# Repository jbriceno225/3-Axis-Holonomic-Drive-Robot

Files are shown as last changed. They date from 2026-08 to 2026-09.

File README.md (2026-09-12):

# KiwiDrive — Three-Wheel Holonomic Robot

A work-in-progress mobile robotics platform built around three omni wheels, an ESP32 controller, quadrature encoders, custom mechanical design, and a ROS 2 workspace.

> **Project status:** active development. The repository contains the current design and software artifacts; physical-system validation is in progress.

## What is in this repository

- **Mechanical design:** Fusion 360 assemblies, STEP exports, and printable STL parts in [`CAD/`](CAD/).
- **Electronics:** KiCad Rev A project files, fabrication outputs, and a purchasing BOM in [`PCB/`](PCB/).
- **Embedded control:** ESP32 firmware for three motor channels, encoder feedback, PID velocity control, Bluetooth gamepad control, and a serial-command safety timeout in [`ESP32_Code/`](ESP32_Code/).
- **ROS 2 integration:** Robot-description files, RViz configuration, serial-command bridge code, and vendor dependencies in [`src/`](src/).

## System overview

```text
Operator / ROS 2 command
          |
          v
  Raspberry Pi + ROS 2 workspace
          |
          v
       Serial interface
          |
          v
ESP32 -> motor drivers -> three DC motors
  ^                              |
  +--------- quadrature encoders-+
```

The three-wheel omni-wheel layout is intended to support holonomic translation and rotation. Current software includes manual control and the foundations for command bridging, robot description, and odometry work.

## Repository layout

```text
CAD/          Fusion 360 sources, STEP exports, and 3D-printable parts
PCB/          Rev A KiCad design, Gerbers, drill files, and BOM
ESP32_Code/   ESP32 firmware
src/          ROS 2 description, serial bridge, and third-party dependencies
patches/      Local patch overlays for selected dependencies
```

## Current development focus

- Integrating ESP32 motor control, encoder feedback, and safety behavior.
- Building out the ROS 2 robot description and serial bridge.
- Validating wheel kinematics, odometry, and hardware behavior through staged testing.
- Documenting CAD, PCB, firmware, and ROS 2 interfaces as the system matures.

## Safety

Test with the drive wheels raised during initial firmware and controller checks. Use an accessible physical power cutoff for floor testing; a software timeout is not a substitute for a physical emergency stop.

## Tools

**Mechanical:** Fusion 360, STEP, STL, 3D printing  
**Electronics:** KiCad, ESP32, TB6612FNG motor drivers, quadrature encoders  
**Software:** C/C++, Python, ROS 2, PID control, serial communication

## License

This project is licensed under the [MIT License](LICENSE).

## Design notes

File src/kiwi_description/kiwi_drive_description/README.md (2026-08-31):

# Kiwi_Drive_Full_Assembly_Copy_Copy — Robot Description

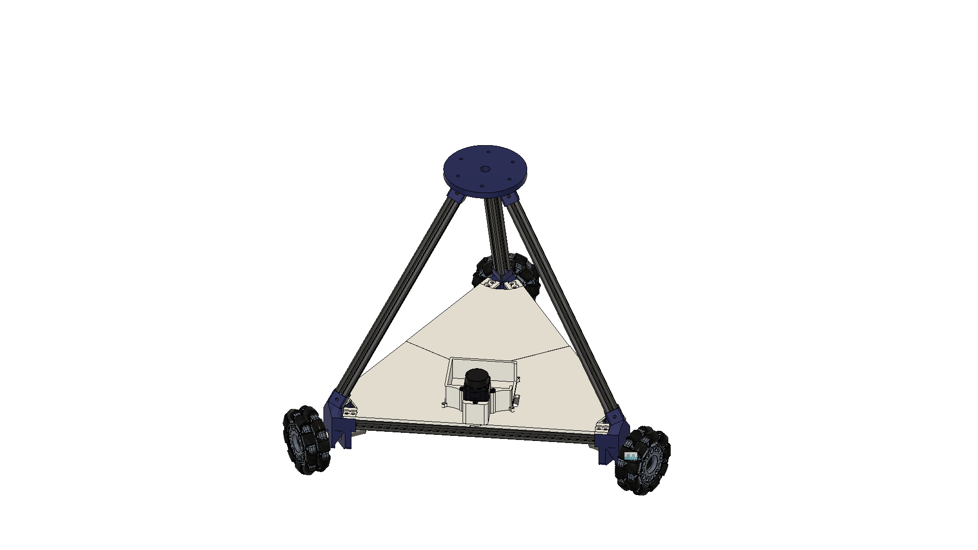
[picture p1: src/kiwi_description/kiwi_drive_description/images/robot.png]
Kiwi_Drive_Full_Assembly_Copy_Copy


## Overview

| Property | Value |
|---|---|
| Total mass | 18.172 kg |
| Links | 5 |
| Joints | 4 (3 movable) |
| Assemblies | 17 |
| Root link | `base_link` |

## Table of Contents

- [Kinematic Tree](#kinematic-tree)
- [Link Properties](#link-properties)
- [Joint Properties](#joint-properties)
- [Assembly Breakdown](#assembly-breakdown)
- [Quick Start (ROS 2)](#quick-start-ros-2)
- [Files](#files)

## Kinematic Tree

```
base_link [BAKE]
  └─ wheel_1_to_base_link [continuous]
    wheel_1_link_Omni_Wheel [BAKE]
  └─ wheel_2_to_base_link [continuous]
    wheel_2_link_Omni_Wheel [BAKE]
  └─ wheel_3_to_base_link [continuous]
    wheel_3_link_Omni_Wheel [BAKE]
  └─ base_link_to_lidar_link [fixed]
    Lidar_Mounting_Plate
```

## Link Properties

| Link | Mass (kg) | Material | Collision | Bodies |
|---|---|---|---|---|
| `Lidar_Mounting_Plate` | 1.0862 | Steel | box | 1 |
| `base_link` | 11.6921 | Steel | box | 1 |
| `wheel_1_link_Omni_Wheel` | 1.7978 | Steel | box | 60 |
| `wheel_2_link_Omni_Wheel` | 1.7978 | Steel | box | 60 |
| `wheel_3_link_Omni_Wheel` | 1.7978 | Steel | box | 60 |

## Joint Properties

| Joint | Type | Parent → Child | Axis | Limits |
|---|---|---|---|---|
| `base_link_to_lidar_link` | fixed | `base_link` → `Lidar_Mounting_Plate` | (0,0,1) | — |
| `wheel_1_to_base_link` | continuous | `base_link` → `wheel_1_link_Omni_Wheel` | (0,0,1) | — |
| `wheel_2_to_base_link` | continuous | `base_link` → `wheel_2_link_Omni_Wheel` | (0,0,1) | — |
| `wheel_3_to_base_link` | continuous | `base_link` → `wheel_3_link_Omni_Wheel` | (0,0,1) | — |

## Assembly Breakdown

### A1_ASM

- **Links**: 
- **Total mass**: 0.000 kg

### Battery_Mount_Assembly

- **Links**: 
- **Total mass**: 0.000 kg

### Converter_DCDC_RECOM_R_78E_0_5_THT

- **Links**: 
- **Total mass**: 0.000 kg

### LD19_LiDAR

- **Links**: 
- **Total mass**: 0.000 kg

### Main_PCB

- **Links**: 
- **Total mass**: 0.000 kg

### OmniWheelwithHub

- **Links**: 
- **Total mass**: 0.000 kg

### Omni_Wheel

- **Links**: 
- **Total mass**: 0.000 kg

### PCB_Housing

- **Links**: 
- **Total mass**: 0.000 kg

### PinHeader_1x02_P2_54mm_Vertical

- **Links**: 
- **Total mass**: 0.000 kg

### PinHeader_1x04_P2_54mm_Vertical

- **Links**: 
- **Total mass**: 0.000 kg

### PinHeader_1x10_P2_54mm_Vertical

- **Links**: 
- **Total mass**: 0.000 kg

### Wheel_Hub

- **Links**: 
- **Total mass**: 0.000 kg

### base_link

- **Links**: base_link
- **Total mass**: 11.692 kg

### lidar_link

- **Links**: Lidar_Mounting_Plate
- **Total mass**: 1.086 kg

### wheel_1_link

- **Links**: wheel_1_link_Omni_Wheel
- **Total mass**: 1.798 kg

### wheel_2_link

- **Links**: wheel_2_link_Omni_Wheel
- **Total mass**: 1.798 kg

### wheel_3_link

- **Links**: wheel_3_link_Omni_Wheel
- **Total mass**: 1.798 kg

## Quick Start (ROS 2)

```bash
# 1. Copy package to your ROS 2 workspace
cp -r kiwi_drive_description ~/ros2_ws/src/

# 2. Build
cd ~/ros2_ws
colcon build --packages-select kiwi_drive_description
source install/setup.bash

# 3. Visualize in RViz2
ros2 launch kiwi_drive_description display.launch.py

# 4. Validate URDF structure
check_urdf install/kiwi_drive_description/share/kiwi_drive_description/urdf/Kiwi_Drive_Full_Assembly_Copy_Copy.urdf

# 5. Print kinematic tree
urdf_to_graphviz install/kiwi_drive_description/share/kiwi_drive_description/urdf/Kiwi_Drive_Full_Assembly_Copy_Copy.urdf
```

**Joint control**: The launch file includes `joint_state_publisher_gui` —
use the sliders to move revolute/prismatic joints in RViz2.

**Topic inspection**:
```bash
# See published joint states
ros2 topic echo /joint_states

# See robot description parameter
ros2 param get /robot_state_publisher robot_description
```

## Files

| Path | Description |
|---|---|
| `urdf/Kiwi_Drive_Full_Assembly_Copy_Copy.urdf.xacro` | Top-level xacro (entry point) |
| `urdf/Kiwi_Drive_Full_Assembly_Copy_Copy.urdf` | Flat URDF (for validation) |
| `urdf/assemblies/` | Per-assembly xacro macros |
| `meshes/` | Visual (OBJ) and collision (STL) meshes |
| `launch/display.launch.py` | Launch robot_state_publisher, RViz, and generated controllers |
| `config/joint_state.yaml` | Joint state publisher config |
| `config/ros2_controllers.yaml` | Generated ros2_control controller manager config |
| `robot_data.yaml` | Supplementary data (beyond URDF) |
| `docs/transforms.md` | Transformation matrices (KaTeX) |

## Customizing

Assemblies tagged `!dummy_` are designed to be swapped out. To replace one:

1. Create your replacement as a xacro macro with the same interface
2. Place it in `urdf/assemblies/`
3. Update the `<xacro:include>` in `urdf/Kiwi_Drive_Full_Assembly_Copy_Copy.urdf.xacro`
4. Update meshes in `meshes/<your_assembly>/`

The xacro prefix system (`${prefix}`) ensures link names stay unique
when multiple instances of the same assembly are used.

---
*Generated by Fusion URDF/XACRO Exporter v3.1.0*

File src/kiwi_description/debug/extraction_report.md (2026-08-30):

# Extraction Report: Kiwi_Drive_Full_Assembly-Copy-Copy

**Exported:** 2026-08-30T14:10:05.508802
**Exporter:** v3.1.0

## Summary

| Metric | Value |
|---|---|
| Occurrences | 201 |
| Subassemblies | 28 |
| Leaf components | 173 |
| Joints (total) | 4 |
| As-built joints | 3 |
| Regular joints | 1 |
| Max nesting depth | 5 |

## Assembly Hierarchy

```
[Kiwi_Drive_Full_Assembly_Copy_Copy]  (design root)
  [base_link]  (depth=0, children=19)
    ├── 2020_400mm_Aluminum_Extrusion  (570.3g, Steel)
    ├── 2020_400mm_Aluminum_Extrusion  (570.3g, Steel)
    ├── 2020_400mm_Aluminum_Extrusion  (570.3g, Steel)
    ├── 2020_400mm_Aluminum_Extrusion  (570.3g, Steel)
    ├── 2020_400mm_Aluminum_Extrusion  (570.3g, Steel)
    ├── 2020_400mm_Aluminum_Extrusion  (570.3g, Steel)
    ├── 2020_Aluminum_Extrusion_Mounting_Spacer  (37.6g, Steel)
    ├── Front_Left_Base_Plate  (1381.7g, Steel)
    ├── Front_Right_Base_Plate  (1387.0g, Steel)
    ├── JGA25_370DC_Motor  (204.4g, Steel)
    ├── JGA25_370DC_Motor  (204.4g, Steel)
    ├── JGA25_370DC_Motor  (204.4g, Steel)
    ├── Motor_Mount  (436.3g, Steel)
    ├── Motor_Mount  (436.3g, Steel)
    ├── Motor_Mount  (436.3g, Steel)
    ├── Rear_Base_Plate  (1396.3g, Steel)
    ├── Top_Plate  (1175.2g, Steel)
    [Battery_Mount_Assembly]  (depth=1, children=2)
      ├── Battery_Mount_Back  (155.2g, Steel)
      ├── Battery_Mount_Front  (106.3g, Steel)
    [PCB_Housing]  (depth=1, children=3)
      ├── PCBoutline  (63.8g, Steel)
      ├── PCM_Mounting_Enclosure  (540.1g, Steel)
      [Main_PCB]  (depth=2, children=5)
        ├── KiwiDrive_PCB  (94.6g, Steel)
        [Converter_DCDC_RECOM_R_78E_0_5_THT]  (depth=3, children=1)
          ├── Converter_DCDC_RECOM_R_78E_05_THT  (8.1g, Steel)
        [PinHeader_1x02_P2_54mm_Vertical]  (depth=3, children=1)
          ├── PinHeader_1x02_P254mm_Vertical  (0.3g, Steel)
        [PinHeader_1x04_P2_54mm_Vertical]  (depth=3, children=1)
          ├── PinHeader_1x04_P254mm_Vertical  (0.6g, Steel)
        [PinHeader_1x10_P2_54mm_Vertical]  (depth=3, children=1)
          ├── PinHeader_1x10_P254mm_Vertical  (1.5g, Steel)
  [lidar_link]  (depth=0, children=2)
    ├── Lidar_Mounting_Plate  (982.9g, Steel)
    [LD19_LiDAR]  (depth=1, children=8)
      ├── LD19_PCB  (8.8g, Steel)
      ├── LD19_bottom  (22.8g, Steel)
      ├── LD19_middle  (51.2g, Steel)
      ├── LD19_up  (20.0g, Steel)
      ├── PA2X6_1  (0.1g, Steel)
      ├── PA2X6_2  (0.1g, Steel)
      ├── PA2X6_3  (0.1g, Steel)
      ├── PA2X6_4  (0.1g, Steel)
  [wheel_1_link]  (depth=0, children=3)
    ├── 4mm_Rigid_Flange_Coupling  (3.5g, Aluminum)
    ├── Omni_Wheel  (1479.8g, Steel)
  [wheel_2_link]  (depth=0, children=3)
    ├── 4mm_Rigid_Flange_Coupling  (3.5g, Aluminum)
    ├── Omni_Wheel  (1479.8g, Steel)
  [wheel_3_link]  (depth=0, children=3)
    ├── 4mm_Rigid_Flange_Coupling  (3.5g, Aluminum)
    ├── Omni_Wheel  (1479.8g, Steel)
    [Wheel_Hub]  (depth=1, children=2)
      ├── Motor_Hub  (119.0g, Steel)
      ├── Motor_Hub  (119.0g, Steel)
      ├── Motor_Hub  (119.0g, Steel)
      [OmniWheelwithHub]  (depth=2, children=3)
        ├── 6mm_Mount  (7.0g, Generic)
        ├── 6mm_Mount  (7.0g, Generic)
        ├── 6mm_Mount  (7.0g, Generic)
        ├── Back_Spacer  (2.4g, Generic)
        ├── Back_Spacer  (2.4g, Generic)
        ├── Back_Spacer  (2.4g, Generic)
        [Omni_Wheel]  (depth=3, children=3)
          ├── F12  (12.4g, Generic)
          ├── F12  (12.4g, Generic)
          ├── F12  (12.4g, Generic)
          [A1_ASM]  (depth=4, children=20)
            ├── F2  (21.2g, Generic)
            ├── F2  (21.2g, Generic)
            ├── F2  (21.2g, Generic)
            ├── F2  (21.2g, Generic)
            ├── F2  (21.2g, Generic)
            ├── F2  (21.2g, Generic)
            ├── F2  (21.2g, Generic)
            ├── F2  (21.2g, Generic)
            ├── F2  (21.2g, Generic)
            ├── F2  (21.2g, Generic)
            ├── F2  (21.2g, Generic)
            ├── F2  (21.2g, Generic)
            ├── F5  (4.8g, Generic)
            ├── F5  (4.8g, Generic)
            ├── F5  (4.8g, Generic)
            ├── F5  (4.8g, Generic)
            ├── F5  (4.8g, Generic)
            ├── F5  (4.8g, Generic)
            ├── F5  (4.8g, Generic)
            ├── F5  (4.8g, Generic)
            ├── F5  (4.8g, Generic)
            ├── F5  (4.8g, Generic)
            ├── F5  (4.8g, Generic)
            ├── F5  (4.8g, Generic)
            ├── F5  (4.8g, Generic)
            ├── F5  (4.8g, Generic)
            ├── F5  (4.8g, Generic)
            ├── F5  (4.8g, Generic)
            ├── F5  (4.8g, Generic)
            ├── F5  (4.8g, Generic)
            ├── F5  (4.8g, Generic)
            ├── F5  (4.8g, Generic)
            ├── F5  (4.8g, Generic)
            ├── F5  (4.8g, Generic)
            ├── F5  (4.8g, Generic)
            ├── F5  (4.8g, Generic)
            ├── F5  (4.8g, Generic)
            ├── F5  (4.8g, Generic)
            ├── F5  (4.8g, Generic)
            ├── F5  (4.8g, Generic)
            ├── F5  (4.8g, Generic)
            ├── F5  (4.8g, Generic)
            ├── F5  (4.8g, Generic)
            ├── F5  (4.8g, Generic)
            ├── F5  (4.8g, Generic)
            ├── F5  (4.8g, Generic)
            ├── F5  (4.8g, Generic)
            ├── F5  (4.8g, Generic)
            ├── F5  (4.8g, Generic)
            ├── F5  (4.8g, Generic)
            ├── F5  (4.8g, Generic)
            ├── F5  (4.8g, Generic)
            ├── F5  (4.8g, Generic)
            ├── F5  (4.8g, Generic)
            ├── F5  (4.8g, Generic)
            ├── F5  (4.8g, Generic)
            ├── F5  (4.8g, Generic)
            ├── F5  (4.8g, Generic)
            ├── F5  (4.8g, Generic)
            ├── F5  (4.8g, Generic)
            ├── F5  (4.8g, Generic)
            ├── F5  (4.8g, Generic)
            ├── F5  (4.8g, Generic)
            ├── F5  (4.8g, Generic)
            ├── F5  (4.8g, Generic)
            ├── F5  (4.8g, Generic)
            ├── F6  (0.2g, Generic)
            ├── F6  (0.2g, Generic)
            ├── F6  (0.2g, Generic)
            ├── F6  (0.2g, Generic)
            ├── F6  (0.2g, Generic)
            ├── F6  (0.2g, Generic)
            ├── F6  (0.2g, Generic)
            ├── F6  (0.2g, Generic)
            ├── F6  (0.2g, Generic)
            ├── F6  (0.2g, Generic)
            ├── F6  (0.2g, Generic)
            ├── F6  (0.2g, Generic)
            ├── F6  (0.2g, Generic)
            ├── F6  (0.2g, Generic)
            ├── F6  (0.2g, Generic)
            ├── F6  (0.2g, Generic)
            ├── F6  (0.2g, Generic)
            ├── F6  (0.2g, Generic)
            ├── F6  (0.2g, Generic)
            ├── F6  (0.2g, Generic)
            ├── F6  (0.2g, Generic)
            ├── F6  (0.2g, Generic)
            ├── F6  (0.2g, Generic)
            ├── F6  (0.2g, Generic)
            ├── F6  (0.2g, Generic)
            ├── F6  (0.2g, Generic)
            ├── F6  (0.2g, Generic)
            ├── F6  (0.2g, Generic)
            ├── F6  (0.2g, Generic)
            ├── F6  (0.2g, Generic)
            ├── F6  (0.2g, Generic)
            ├── F6  (0.2g, Generic)
            ├── F6  (0.2g, Generic)
            ├── F6  (0.2g, Generic)
            ├── F6  (0.2g, Generic)
            ├── F6  (0.2g, Generic)
            ├── F6  (0.2g, Generic)
            ├── F6  (0.2g, Generic)
            ├── F6  (0.2g, Generic)
            ├── F6  (0.2g, Generic)
            ├── F6  (0.2g, Generic)
            ├── F6  (0.2g, Generic)
            ├── F6  (0.2g, Generic)
            ├── F6  (0.2g, Generic)
            ├── F6  (0.2g, Generic)
            ├── F6  (0.2g, Generic)
            ├── F6  (0.2g, Generic)
            ├── F6  (0.2g, Generic)
            ├── F6  (0.2g, Generic)
            ├── F6  (0.2g, Generic)
            ├── F6  (0.2g, Generic)
            ├── F6  (0.2g, Generic)
            ├── F6  (0.2g, Generic)
            ├── F6  (0.2g, Generic)
```

## Occurrences

### Depth 0

#### 📦 SUBASSEMBLY: `base_link`

| Property | Value |
|---|---|
| Full path | `base_link:1` |
| Component name | base_link |
| Depth | 0 |
| Path segments | base_link |
| Child occurrences | 19 |
| **Transforms** | |
| Global position (m) | (0.000000, 0.000000, 0.000000) |
| Global position (mm) | (0.00, 0.00, 0.00) |
| Local transform (m) | (0.000000, 0.000000, 0.000000) |
| Assembly context depth | 0 |
| transform2 (m) | (0.000000, 0.000000, 0.000000) |

#### 📦 SUBASSEMBLY: `lidar_link`

| Property | Value |
|---|---|
| Full path | `lidar_link:1` |
| Component name | lidar_link |
| Depth | 0 |
| Path segments | lidar_link |
| Child occurrences | 2 |
| **Transforms** | |
| Global position (m) | (-0.000000, -0.000885, -0.000101) |
| Global position (mm) | (-0.00, -0.88, -0.10) |
| Local transform (m) | (-0.000000, -0.000885, -0.000101) |
| Assembly context depth | 0 |
| transform2 (m) | (-0.000000, -0.000885, -0.000101) |

#### 📦 SUBASSEMBLY: `wheel_1_link`

| Property | Value |
|---|---|
| Full path | `wheel_1_link:1` |
| Component name | wheel_1_link |
| Depth | 0 |
| Path segments | wheel_1_link |
| Child occurrences | 3 |
| **Transforms** | |
| Global position (m) | (0.000000, 0.000000, 0.000000) |
| Global position (mm) | (0.00, 0.00, 0.00) |
| Local transform (m) | (0.000000, 0.000000, 0.000000) |
| Assembly context depth | 0 |
| transform2 (m) | (0.000000, 0.000000, 0.000000) |

#### 📦 SUBASSEMBLY: `wheel_2_link`

| Property | Value |
|---|---|
| Full path | `wheel_2_link:1` |
| Component name | wheel_2_link |
| Depth | 0 |
| Path segments | wheel_2_link |
| Child occurrences | 3 |
| **Transforms** | |
| Global position (m) | (0.000000, 0.000000, 0.000000) |
| Global position (mm) | (0.00, 0.00, 0.00) |
| Local transform (m) | (0.000000, 0.000000, 0.000000) |
| Assembly context depth | 0 |
| transform2 (m) | (0.000000, 0.000000, 0.000000) |

#### 📦 SUBASSEMBLY: `wheel_3_link`

| Property | Value |
|---|---|
| Full path | `wheel_3_link:1` |
| Component name | wheel_3_link |
| Depth | 0 |
| Path segments | wheel_3_link |
| Child occurrences | 3 |
| **Transforms** | |
| Global position (m) | (0.000000, 0.000000, 0.000000) |
| Global position (mm) | (0.00, 0.00, 0.00) |
| Local transform (m) | (0.000000, 0.000000, 0.000000) |
| Assembly context depth | 0 |
| transform2 (m) | (0.000000, 0.000000, 0.000000) |

### Depth 1

#### 🔧 COMPONENT: `2020_400mm_Aluminum_Extrusion`

| Property | Value |
|---|---|
| Full path | `base_link:1+2020_400mm_Aluminum_Extrusion:1` |
| Component name | 2020_400mm_Aluminum_Extrusion |
| Depth | 1 |
| Path segments | base_link → 2020_400mm_Aluminum_Extrusion |
| Parent path | `base_link:1` |
| **Transforms** | |
| Global position (m) | (-0.180000, -0.129904, -0.000000) |
| Global position (mm) | (-180.00, -129.90, -0.00) |
| Local transform (m) | (-0.180000, -0.129904, -0.000000) |
| Assembly context depth | 1 |
| transform2 (m) | (-0.180000, -0.129904, -0.000000) |
| **Physical** | |
| Mass | 0.570259 kg (570.259 g) |
| Volume | 7.264445e-05 m³ |
| Density | 7850.0 kg/m³ |
| Surface area | 6.785414e-02 m² |
| Body count | 1 |
| CoM (component-local, m) | (0.000000, 0.180000, 0.000000) |
| CoM (global, m) | (-0.180000, 0.050096, 0.000000) |
| CoM (global, mm) | (-180.00, 50.10, 0.00) |
| **Inertia at origin (kg·m²)** | |
| Ixx, Iyy, Izz | 2.610302e-02, 4.636788e-05, 2.610302e-02 |
| Ixy, Ixz, Iyz | -4.801159e-12, 1.977162e-13, 2.096710e-13 |
| **Inertia at CoM (kg·m²)** | |
| Ixx, Iyy, Izz | 7.626636e-03, 4.636788e-05, 7.626636e-03 |
| Ixy, Ixz, Iyz | -7.710703e-13, 1.977162e-13, 5.725726e-12 |
| Bounding box (m) | 0.0200 × 0.4000 × 0.0200 |
| Bounding box (mm) | 20.00 × 400.00 × 20.00 |
| **Material & Appearance** | |
| Material | Steel |
| Appearance | Paint_Metallic_Black |
| Color (RGB 0-1) | (0.349, 0.349, 0.349) |
| Color (RGB 0-255) | (89, 89, 89) |

#### 🔧 COMPONENT: `2020_400mm_Aluminum_Extrusion`

| Property | Value |
|---|---|
| Full path | `base_link:1+2020_400mm_Aluminum_Extrusion:4` |
| Component name | 2020_400mm_Aluminum_Extrusion |
| Depth | 1 |
| Path segments | base_link → 2020_400mm_Aluminum_Extrusion |
| Parent path | `base_link:1` |
| **Transforms** | |
| Global position (m) | (-0.202500, -0.090933, 0.000000) |
| Global position (mm) | (-202.50, -90.93, 0.00) |
| Local transform (m) | (-0.202500, -0.090933, 0.000000) |
| Assembly context depth | 1 |
| transform2 (m) | (-0.202500, -0.090933, 0.000000) |
| **Physical** | |
| Mass | 0.570259 kg (570.259 g) |
| Volume | 7.264445e-05 m³ |
| Density | 7850.0 kg/m³ |
| Surface area | 6.785414e-02 m² |
| Body count | 1 |
| CoM (component-local, m) | (0.000000, 0.180000, 0.000000) |
| CoM (global, m) | (-0.202500, 0.089067, 0.000000) |
| CoM (global, mm) | (-202.50, 89.07, 0.00) |
| **Inertia at origin (kg·m²)** | |
| Ixx, Iyy, Izz | 2.610302e-02, 4.636788e-05, 2.610302e-02 |
| Ixy, Ixz, Iyz | -4.801159e-12, 1.977162e-13, 2.096710e-13 |
| **Inertia at CoM (kg·m²)** | |
| Ixx, Iyy, Izz | 7.626636e-03, 4.636788e-05, 7.626636e-03 |
| Ixy, Ixz, Iyz | -7.710703e-13, 1.977162e-13, 5.725726e-12 |
| Bounding box (m) | 0.0200 × 0.4000 × 0.0200 |
| Bounding box (mm) | 20.00 × 400.00 × 20.00 |
| **Material & Appearance** | |
| Material | Steel |
| Appearance | Paint_Metallic_Black |
| Color (RGB 0-1) | (0.349, 0.349, 0.349) |
| Color (RGB 0-255) | (89, 89, 89) |

#### 🔧 COMPONENT: `2020_400mm_Aluminum_Extrusion`

| Property | Value |
|---|---|
| Full path | `base_link:1+2020_400mm_Aluminum_Extrusion:5` |
| Component name | 2020_400mm_Aluminum_Extrusion |
| Depth | 1 |
| Path segments | base_link → 2020_400mm_Aluminum_Extrusion |
| Parent path | `base_link:1` |
| **Transforms** | |
| Global position (m) | (0.202500, -0.090933, 0.000000) |
| Global position (mm) | (202.50, -90.93, 0.00) |
| Local transform (m) | (0.202500, -0.090933, 0.000000) |
| Assembly context depth | 1 |
| transform2 (m) | (0.202500, -0.090933, 0.000000) |
| **Physical** | |
| Mass | 0.570259 kg (570.259 g) |
| Volume | 7.264445e-05 m³ |
| Density | 7850.0 kg/m³ |
| Surface area | 6.785414e-02 m² |
| Body count | 1 |
| CoM (component-local, m) | (0.000000, 0.180000, 0.000000) |
| CoM (global, m) | (0.202500, 0.089067, 0.000000) |
| CoM (global, mm) | (202.50, 89.07, 0.00) |
| **Inertia at origin (kg·m²)** | |
| Ixx, Iyy, Izz | 2.610302e-02, 4.636788e-05, 2.610302e-02 |
| Ixy, Ixz, Iyz | -4.801159e-12, 1.977162e-13, 2.096710e-13 |
| **Inertia at CoM (kg·m²)** | |
| Ixx, Iyy, Izz | 7.626636e-03, 4.636788e-05, 7.626636e-03 |
| Ixy, Ixz, Iyz | -7.710703e-13, 1.977162e-13, 5.725726e-12 |
| Bounding box (m) | 0.0200 × 0.4000 × 0.0200 |
| Bounding box (mm) | 20.00 × 400.00 × 20.00 |
| **Material & Appearance** | |
| Material | Steel |
| Appearance | Paint_Metallic_Black |
| Color (RGB 0-1) | (0.349, 0.349, 0.349) |
| Color (RGB 0-255) | (89, 89, 89) |

#### 🔧 COMPONENT: `2020_400mm_Aluminum_Extrusion`

| Property | Value |
|---|---|
| Full path | `base_link:1+2020_400mm_Aluminum_Extrusion:7` |
| Component name | 2020_400mm_Aluminum_Extrusion |
| Depth | 1 |
| Path segments | base_link → 2020_400mm_Aluminum_Extrusion |
| Parent path | `base_link:1` |
| **Transforms** | |
| Global position (m) | (0.202839, -0.117109, 0.041859) |
| Global position (mm) | (202.84, -117.11, 41.86) |
| Local transform (m) | (0.202839, -0.117109, 0.041859) |
| Assembly context depth | 1 |
| transform2 (m) | (0.202839, -0.117109, 0.041859) |
| **Physical** | |
| Mass | 0.570259 kg (570.259 g) |
| Volume | 7.264445e-05 m³ |
| Density | 7850.0 kg/m³ |
| Surface area | 6.785414e-02 m² |
| Body count | 1 |
| CoM (component-local, m) | (0.000000, 0.180000, 0.000000) |
| CoM (global, m) | (0.202839, 0.062891, 0.041859) |
| CoM (global, mm) | (202.84, 62.89, 41.86) |
| **Inertia at origin (kg·m²)** | |
| Ixx, Iyy, Izz | 2.610302e-02, 4.636788e-05, 2.610302e-02 |
| Ixy, Ixz, Iyz | -4.801159e-12, 1.977162e-13, 2.096710e-13 |
| **Inertia at CoM (kg·m²)** | |
| Ixx, Iyy, Izz | 7.626636e-03, 4.636788e-05, 7.626636e-03 |
| Ixy, Ixz, Iyz | -7.710703e-13, 1.977162e-13, 5.725726e-12 |
| Bounding box (m) | 0.0200 × 0.4000 × 0.0200 |
| Bounding box (mm) | 20.00 × 400.00 × 20.00 |
| **Material & Appearance** | |
| Material | Steel |
| Appearance | Paint_Metallic_Black |
| Color (RGB 0-1) | (0.349, 0.349, 0.349) |
| Color (RGB 0-255) | (89, 89, 89) |

#### 🔧 COMPONENT: `2020_400mm_Aluminum_Extrusion`

| Property | Value |
|---|---|
| Full path | `base_link:1+2020_400mm_Aluminum_Extrusion:8` |
| Component name | 2020_400mm_Aluminum_Extrusion |
| Depth | 1 |
| Path segments | base_link → 2020_400mm_Aluminum_Extrusion |
| Parent path | `base_link:1` |
| **Transforms** | |
| Global position (m) | (-0.202839, -0.117109, 0.041859) |
| Global position (mm) | (-202.84, -117.11, 41.86) |
| Local transform (m) | (-0.202839, -0.117109, 0.041859) |
| Assembly context depth | 1 |
| transform2 (m) | (-0.202839, -0.117109, 0.041859) |
| **Physical** | |
| Mass | 0.570259 kg (570.259 g) |
| Volume | 7.264445e-05 m³ |
| Density | 7850.0 kg/m³ |
| Surface area | 6.785414e-02 m² |
| Body count | 1 |
| CoM (component-local, m) | (0.000000, 0.180000, 0.000000) |
| CoM (global, m) | (-0.202839, 0.062891, 0.041859) |
| CoM (global, mm) | (-202.84, 62.89, 41.86) |
| **Inertia at origin (kg·m²)** | |
| Ixx, Iyy, Izz | 2.610302e-02, 4.636788e-05, 2.610302e-02 |
| Ixy, Ixz, Iyz | -4.801159e-12, 1.977162e-13, 2.096710e-13 |
| **Inertia at CoM (kg·m²)** | |
| Ixx, Iyy, Izz | 7.626636e-03, 4.636788e-05, 7.626636e-03 |
| Ixy, Ixz, Iyz | -7.710703e-13, 1.977162e-13, 5.725726e-12 |
| Bounding box (m) | 0.0200 × 0.4000 × 0.0200 |
| Bounding box (mm) | 20.00 × 400.00 × 20.00 |
| **Material & Appearance** | |
| Material | Steel |
| Appearance | Paint_Metallic_Black |
| Color (RGB 0-1) | (0.349, 0.349, 0.349) |
| Color (RGB 0-255) | (89, 89, 89) |

#### 🔧 COMPONENT: `2020_400mm_Aluminum_Extrusion`

| Property | Value |
|---|---|
| Full path | `base_link:1+2020_400mm_Aluminum_Extrusion:9` |
| Component name | 2020_400mm_Aluminum_Extrusion |
| Depth | 1 |
| Path segments | base_link → 2020_400mm_Aluminum_Extrusion |
| Parent path | `base_link:1` |
| **Transforms** | |
| Global position (m) | (0.000000, 0.046452, 0.349013) |
| Global position (mm) | (0.00, 46.45, 349.01) |
| Local transform (m) | (0.000000, 0.046452, 0.349013) |
| Assembly context depth | 1 |
| transform2 (m) | (0.000000, 0.046452, 0.349013) |
| **Physical** | |
| Mass | 0.570259 kg (570.259 g) |
| Volume | 7.264445e-05 m³ |
| Density | 7850.0 kg/m³ |
| Surface area | 6.785414e-02 m² |
| Body count | 1 |
| CoM (component-local, m) | (0.000000, 0.180000, 0.000000) |
| CoM (global, m) | (0.000000, 0.226452, 0.349013) |
| CoM (global, mm) | (0.00, 226.45, 349.01) |
| **Inertia at origin (kg·m²)** | |
| Ixx, Iyy, Izz | 2.610302e-02, 4.636788e-05, 2.610302e-02 |
| Ixy, Ixz, Iyz | -4.801159e-12, 1.977162e-13, 2.096710e-13 |
| **Inertia at CoM (kg·m²)** | |
| Ixx, Iyy, Izz | 7.626636e-03, 4.636788e-05, 7.626636e-03 |
| Ixy, Ixz, Iyz | -7.710703e-13, 1.977162e-13, 5.725726e-12 |
| Bounding box (m) | 0.0200 × 0.4000 × 0.0200 |
| Bounding box (mm) | 20.00 × 400.00 × 20.00 |
| **Material & Appearance** | |
| Material | Steel |
| Appearance | Paint_Metallic_Black |
| Color (RGB 0-1) | (0.349, 0.349, 0.349) |
| Color (RGB 0-255) | (89, 89, 89) |

#### 🔧 COMPONENT: `2020_Aluminum_Extrusion_Mounting_Spacer`

| Property | Value |
|---|---|
| Full path | `base_link:1+2020_Aluminum_Extrusion_Mounting_Spacer:1` |
| Component name | 2020_Aluminum_Extrusion_Mounting_Spacer |
| Depth | 1 |
| Path segments | base_link → 2020_Aluminum_Extrusion_Mounting_Spacer |
| Parent path | `base_link:1` |
| **Transforms** | |
| Global position (m) | (0.000000, 0.000000, 0.000000) |
| Global position (mm) | (0.00, 0.00, 0.00) |
| Local transform (m) | (0.000000, 0.000000, 0.000000) |
| Assembly context depth | 1 |
| transform2 (m) | (0.000000, 0.000000, 0.000000) |
| **Physical** | |
| Mass | 0.037605 kg (37.605 g) |
| Volume | 4.790506e-06 m³ |
| Density | 7850.0 kg/m³ |
| Surface area | 4.372256e-03 m² |
| Body count | 1 |
| CoM (component-local, m) | (0.167312, -0.029986, 0.006108) |
| CoM (global, m) | (0.167312, -0.029986, 0.006108) |
| CoM (global, mm) | (167.31, -29.99, 6.11) |
| **Inertia at origin (kg·m²)** | |
| Ixx, Iyy, Izz | 1.120928e-04, 1.079906e-03, 1.189125e-03 |
| Ixy, Ixz, Iyz | 2.329061e-04, -3.842921e-05, 6.887371e-06 |
| **Inertia at CoM (kg·m²)** | |
| Ixx, Iyy, Izz | 7.687634e-05, 2.579536e-05, 1.026034e-04 |
| Ixy, Ixz, Iyz | 4.423742e-05, -1.084202e-19, 2.371692e-20 |
| Bounding box (m) | 0.0995 × 0.1618 × 0.0035 |
| Bounding box (mm) | 99.47 × 161.78 × 3.49 |
| **Material & Appearance** | |
| Material | Steel |
| Appearance | Steel_Satin |
| Color (RGB 0-1) | (0.627, 0.627, 0.627) |
| Color (RGB 0-255) | (160, 160, 160) |

#### 📦 SUBASSEMBLY: `Battery_Mount_Assembly`

| Property | Value |
|---|---|
| Full path | `base_link:1+Battery_Mount_Assembly:1` |
| Component name | Battery_Mount_Assembly |
| Depth | 1 |
| Path segments | base_link → Battery_Mount_Assembly |
| Parent path | `base_link:1` |
| Child occurrences | 2 |
| **Transforms** | |
| Global position (m) | (-0.070000, -0.080000, -0.020750) |
| Global position (mm) | (-70.00, -80.00, -20.75) |
| Local transform (m) | (-0.070000, -0.080000, -0.020750) |
| Assembly context depth | 1 |
| transform2 (m) | (-0.070000, -0.080000, -0.020750) |

#### 🔧 COMPONENT: `Front_Left_Base_Plate`

| Property | Value |
|---|---|
| Full path | `base_link:1+Front_Left_Base_Plate:1` |
| Component name | Front_Left_Base_Plate |
| Depth | 1 |
| Path segments | base_link → Front_Left_Base_Plate |
| Parent path | `base_link:1` |
| **Transforms** | |
| Global position (m) | (0.000650, 0.000064, 0.000000) |
| Global position (mm) | (0.65, 0.06, 0.00) |
| Local transform (m) | (0.000650, 0.000064, 0.000000) |
| Assembly context depth | 1 |
| transform2 (m) | (0.000650, 0.000064, 0.000000) |
| **Physical** | |
| Mass | 1.381733 kg (1381.733 g) |
| Volume | 1.760169e-04 m³ |
| Density | 7850.0 kg/m³ |
| Surface area | 7.527908e-02 m² |
| Body count | 1 |
| CoM (component-local, m) | (-0.095843, -0.056087, 0.013009) |
| CoM (global, m) | (-0.095193, -0.056023, 0.013009) |
| CoM (global, mm) | (-95.19, -56.02, 13.01) |
| **Inertia at origin (kg·m²)** | |
| Ixx, Iyy, Izz | 8.315368e-03, 1.690035e-02, 2.474131e-02 |
| Ixy, Ixz, Iyz | -7.578696e-03, 1.719741e-03, 1.015347e-03 |
| **Inertia at CoM (kg·m²)** | |
| Ixx, Iyy, Izz | 3.735008e-03, 3.974013e-03, 7.702282e-03 |
| Ixy, Ixz, Iyz | -1.511609e-04, -3.029761e-06, 7.197683e-06 |
| Bounding box (m) | 0.2301 × 0.2190 × 0.0054 |
| Bounding box (mm) | 230.09 × 219.04 × 5.43 |
| **Material & Appearance** | |
| Material | Steel |
| Appearance | Plastic_Translucent_Glossy_White |
| Color (RGB 0-1) | (1.000, 1.000, 1.000) |
| Color (RGB 0-255) | (255, 255, 255) |

#### 🔧 COMPONENT: `Front_Right_Base_Plate`

| Property | Value |
|---|---|
| Full path | `base_link:1+Front_Right_Base_Plate:1` |
| Component name | Front_Right_Base_Plate |
| Depth | 1 |
| Path segments | base_link → Front_Right_Base_Plate |
| Parent path | `base_link:1` |
| **Transforms** | |
| Global position (m) | (0.000000, 0.000000, 0.000000) |
| Global position (mm) | (0.00, 0.00, 0.00) |
| Local transform (m) | (0.000000, 0.000000, 0.000000) |
| Assembly context depth | 1 |
| transform2 (m) | (0.000000, 0.000000, 0.000000) |
| **Physical** | |
| Mass | 1.387013 kg (1387.013 g) |
| Volume | 1.766895e-04 m³ |
| Density | 7850.0 kg/m³ |
| Surface area | 7.586567e-02 m² |
| Body count | 1 |
| CoM (component-local, m) | (-0.096008, -0.055285, 0.013006) |
| CoM (global, m) | (-0.096008, -0.055285, 0.013006) |
| CoM (global, mm) | (-96.01, -55.28, 13.01) |
| **Inertia at origin (kg·m²)** | |
| Ixx, Iyy, Izz | 8.254471e-03, 1.695557e-02, 2.473400e-02 |
| Ixy, Ixz, Iyz | -7.532192e-03, 1.729350e-03, 1.004789e-03 |
| **Inertia at CoM (kg·m²)** | |
| Ixx, Iyy, Izz | 3.780590e-03, 3.936143e-03, 7.709962e-03 |
| Ixy, Ixz, Iyz | -1.702698e-04, -2.627156e-06, 7.456860e-06 |
| Bounding box (m) | 0.2301 × 0.2190 × 0.0054 |
| Bounding box (mm) | 230.09 × 219.04 × 5.43 |
| **Material & Appearance** | |
| Material | Steel |
| Appearance | Plastic_Translucent_Glossy_White |
| Color (RGB 0-1) | (1.000, 1.000, 1.000) |
| Color (RGB 0-255) | (255, 255, 255) |

#### 🔧 COMPONENT: `JGA25_370DC_Motor`

| Property | Value |
|---|---|
| Full path | `base_link:1+JGA25-370DC_Motor:1` |
| Component name | JGA25-370DC_Motor |
| Depth | 1 |
| Path segments | base_link → JGA25_370DC_Motor |
| Parent path | `base_link:1` |
| **Transforms** | |
| Global position (m) | (0.184042, -0.106257, -0.028962) |
| Global position (mm) | (184.04, -106.26, -28.96) |
| Local transform (m) | (0.184042, -0.106257, -0.028962) |
| Assembly context depth | 1 |
| transform2 (m) | (0.184042, -0.106257, -0.028962) |
| **Physical** | |
| Mass | 0.204417 kg (204.417 g) |
| Volume | 2.604041e-05 m³ |
| Density | 7850.0 kg/m³ |
| Surface area | 5.817057e-03 m² |
| Body count | 1 |
| CoM (component-local, m) | (0.016564, -0.000001, 0.000000) |
| CoM (global, m) | (0.200606, -0.106257, -0.028962) |
| CoM (global, mm) | (200.61, -106.26, -28.96) |
| **Inertia at origin (kg·m²)** | |
| Ixx, Iyy, Izz | 1.523969e-05, 1.164318e-04, 1.164264e-04 |
| Ixy, Ixz, Iyz | 5.889723e-09, -7.638408e-15, -8.812862e-19 |
| **Inertia at CoM (kg·m²)** | |
| Ixx, Iyy, Izz | 1.523969e-05, 6.034839e-05, 6.034290e-05 |
| Ixy, Ixz, Iyz | 3.968356e-09, 1.297842e-16, -1.147417e-18 |
| Bounding box (m) | 0.0705 × 0.0252 × 0.0252 |
| Bounding box (mm) | 70.50 × 25.20 × 25.20 |
| **Material & Appearance** | |
| Material | Steel |
| Appearance | Steel_Satin |
| Color (RGB 0-1) | (0.627, 0.627, 0.627) |
| Color (RGB 0-255) | (160, 160, 160) |

#### 🔧 COMPONENT: `JGA25_370DC_Motor`

| Property | Value |
|---|---|
| Full path | `base_link:1+JGA25-370DC_Motor:2` |
| Component name | JGA25-370DC_Motor |
| Depth | 1 |
| Path segments | base_link → JGA25_370DC_Motor |
| Parent path | `base_link:1` |
| **Transforms** | |
| Global position (m) | (-0.184042, -0.106257, -0.028962) |
| Global position (mm) | (-184.04, -106.26, -28.96) |
| Local transform (m) | (-0.184042, -0.106257, -0.028962) |
| Assembly context depth | 1 |
| transform2 (m) | (-0.184042, -0.106257, -0.028962) |
| **Physical** | |
| Mass | 0.204417 kg (204.417 g) |
| Volume | 2.604041e-05 m³ |
| Density | 7850.0 kg/m³ |
| Surface area | 5.817057e-03 m² |
| Body count | 1 |
| CoM (component-local, m) | (0.016564, -0.000001, 0.000000) |
| CoM (global, m) | (-0.167478, -0.106257, -0.028962) |
| CoM (global, mm) | (-167.48, -106.26, -28.96) |
| **Inertia at origin (kg·m²)** | |
| Ixx, Iyy, Izz | 1.523969e-05, 1.164318e-04, 1.164264e-04 |
| Ixy, Ixz, Iyz | 5.889723e-09, -7.638408e-15, -8.812862e-19 |
| **Inertia at CoM (kg·m²)** | |
| Ixx, Iyy, Izz | 1.523969e-05, 6.034839e-05, 6.034290e-05 |
| Ixy, Ixz, Iyz | 3.968356e-09, 1.297842e-16, -1.147417e-18 |
| Bounding box (m) | 0.0705 × 0.0252 × 0.0252 |
| Bounding box (mm) | 70.50 × 25.20 × 25.20 |
| **Material & Appearance** | |
| Material | Steel |
| Appearance | Steel_Satin |
| Color (RGB 0-1) | (0.627, 0.627, 0.627) |
| Color (RGB 0-255) | (160, 160, 160) |

#### 🔧 COMPONENT: `JGA25_370DC_Motor`

| Property | Value |
|---|---|
| Full path | `base_link:1+JGA25-370DC_Motor:3` |
| Component name | JGA25-370DC_Motor |
| Depth | 1 |
| Path segments | base_link → JGA25_370DC_Motor |
| Parent path | `base_link:1` |
| **Transforms** | |
| Global position (m) | (-0.000000, 0.212513, -0.028962) |
| Global position (mm) | (-0.00, 212.51, -28.96) |
| Local transform (m) | (-0.000000, 0.212513, -0.028962) |
| Assembly context depth | 1 |
| transform2 (m) | (-0.000000, 0.212513, -0.028962) |
| **Physical** | |
| Mass | 0.204417 kg (204.417 g) |
| Volume | 2.604041e-05 m³ |
| Density | 7850.0 kg/m³ |
| Surface area | 5.817057e-03 m² |
| Body count | 1 |
| CoM (component-local, m) | (0.016564, -0.000001, 0.000000) |
| CoM (global, m) | (0.016564, 0.212513, -0.028962) |
| CoM (global, mm) | (16.56, 212.51, -28.96) |
| **Inertia at origin (kg·m²)** | |
| Ixx, Iyy, Izz | 1.523969e-05, 1.164318e-04, 1.164264e-04 |
| Ixy, Ixz, Iyz | 5.889723e-09, -7.638408e-15, -8.812862e-19 |
| **Inertia at CoM (kg·m²)** | |
| Ixx, Iyy, Izz | 1.523969e-05, 6.034839e-05, 6.034290e-05 |
| Ixy, Ixz, Iyz | 3.968356e-09, 1.297842e-16, -1.147417e-18 |
| Bounding box (m) | 0.0705 × 0.0252 × 0.0252 |
| Bounding box (mm) | 70.50 × 25.20 × 25.20 |
| **Material & Appearance** | |
| Material | Steel |
| Appearance | Steel_Satin |
| Color (RGB 0-1) | (0.627, 0.627, 0.627) |
| Color (RGB 0-255) | (160, 160, 160) |

#### 🔧 COMPONENT: `Motor_Mount`

| Property | Value |
|---|---|
| Full path | `base_link:1+Motor_Mount:1` |
| Component name | Motor_Mount |
| Depth | 1 |
| Path segments | base_link → Motor_Mount |
| Parent path | `base_link:1` |
| **Transforms** | |
| Global position (m) | (0.000000, 0.000000, 0.000000) |
| Global position (mm) | (0.00, 0.00, 0.00) |
| Local transform (m) | (0.000000, 0.000000, 0.000000) |
| Assembly context depth | 1 |
| transform2 (m) | (0.000000, 0.000000, 0.000000) |
| **Physical** | |
| Mass | 0.436296 kg (436.296 g) |
| Volume | 5.557905e-05 m³ |
| Density | 7850.0 kg/m³ |
| Surface area | 2.534180e-02 m² |
| Body count | 1 |
| CoM (component-local, m) | (0.209969, -0.121243, -0.002628) |
| CoM (global, m) | (0.209969, -0.121243, -0.002628) |
| CoM (global, mm) | (209.97, -121.24, -2.63) |
| **Inertia at origin (kg·m²)** | |
| Ixx, Iyy, Izz | 6.662523e-03, 1.946299e-02, 2.576619e-02 |
| Ixy, Ixz, Iyz | 1.108830e-02, 2.341606e-04, -1.351766e-04 |
| **Inertia at CoM (kg·m²)** | |
| Ixx, Iyy, Izz | 2.460108e-04, 2.250943e-04, 1.178017e-04 |
| Ixy, Ixz, Iyz | -1.858532e-05, -6.560872e-06, 3.824312e-06 |
| Bounding box (m) | 0.0508 × 0.0565 × 0.0958 |
| Bounding box (mm) | 50.79 × 56.54 × 95.78 |
| **Material & Appearance** | |
| Material | Steel |
| Appearance | ABS_White_1 |
| Color (RGB 0-1) | (0.075, 0.129, 0.502) |
| Color (RGB 0-255) | (19, 33, 128) |

#### 🔧 COMPONENT: `Motor_Mount`

| Property | Value |
|---|---|
| Full path | `base_link:1+Motor_Mount:2` |
| Component name | Motor_Mount |
| Depth | 1 |
| Path segments | base_link → Motor_Mount |
| Parent path | `base_link:1` |
| **Transforms** | |
| Global position (m) | (-0.000000, 0.000000, -0.000000) |
| Global position (mm) | (-0.00, 0.00, -0.00) |
| Local transform (m) | (-0.000000, 0.000000, -0.000000) |
| Assembly context depth | 1 |
| transform2 (m) | (-0.000000, 0.000000, -0.000000) |
| **Physical** | |
| Mass | 0.436296 kg (436.296 g) |
| Volume | 5.557905e-05 m³ |
| Density | 7850.0 kg/m³ |
| Surface area | 2.534180e-02 m² |
| Body count | 1 |
| CoM (component-local, m) | (0.209969, -0.121243, -0.002628) |
| CoM (global, m) | (0.209969, -0.121243, -0.002628) |
| CoM (global, mm) | (209.97, -121.24, -2.63) |
| **Inertia at origin (kg·m²)** | |
| Ixx, Iyy, Izz | 6.662523e-03, 1.946299e-02, 2.576619e-02 |
| Ixy, Ixz, Iyz | 1.108830e-02, 2.341606e-04, -1.351766e-04 |
| **Inertia at CoM (kg·m²)** | |
| Ixx, Iyy, Izz | 2.460108e-04, 2.250943e-04, 1.178017e-04 |
| Ixy, Ixz, Iyz | -1.858532e-05, -6.560872e-06, 3.824312e-06 |
| Bounding box (m) | 0.0508 × 0.0565 × 0.0958 |
| Bounding box (mm) | 50.79 × 56.54 × 95.78 |
| **Material & Appearance** | |
| Material | Steel |
| Appearance | ABS_White_1 |
| Color (RGB 0-1) | (0.075, 0.129, 0.502) |
| Color (RGB 0-255) | (19, 33, 128) |

#### 🔧 COMPONENT: `Motor_Mount`

| Property | Value |
|---|---|
| Full path | `base_link:1+Motor_Mount:3` |
| Component name | Motor_Mount |
| Depth | 1 |
| Path segments | base_link → Motor_Mount |
| Parent path | `base_link:1` |
| **Transforms** | |
| Global position (m) | (-0.000000, 0.000000, 0.000000) |
| Global position (mm) | (-0.00, 0.00, 0.00) |
| Local transform (m) | (-0.000000, 0.000000, 0.000000) |
| Assembly context depth | 1 |
| transform2 (m) | (-0.000000, 0.000000, 0.000000) |
| **Physical** | |
| Mass | 0.436296 kg (436.296 g) |
| Volume | 5.557905e-05 m³ |
| Density | 7850.0 kg/m³ |
| Surface area | 2.534180e-02 m² |
| Body count | 1 |
| CoM (component-local, m) | (0.209969, -0.121243, -0.002628) |
| CoM (global, m) | (0.209969, -0.121243, -0.002628) |
| CoM (global, mm) | (209.97, -121.24, -2.63) |
| **Inertia at origin (kg·m²)** | |
| Ixx, Iyy, Izz | 6.662523e-03, 1.946299e-02, 2.576619e-02 |
| Ixy, Ixz, Iyz | 1.108830e-02, 2.341606e-04, -1.351766e-04 |
| **Inertia at CoM (kg·m²)** | |
| Ixx, Iyy, Izz | 2.460108e-04, 2.250943e-04, 1.178017e-04 |
| Ixy, Ixz, Iyz | -1.858532e-05, -6.560872e-06, 3.824312e-06 |
| Bounding box (m) | 0.0508 × 0.0565 × 0.0958 |
| Bounding box (mm) | 50.79 × 56.54 × 95.78 |
| **Material & Appearance** | |
| Material | Steel |
| Appearance | ABS_White_1 |
| Color (RGB 0-1) | (0.075, 0.129, 0.502) |
| Color (RGB 0-255) | (19, 33, 128) |

#### 📦 SUBASSEMBLY: `PCB_Housing`

| Property | Value |
|---|---|
| Full path | `base_link:1+PCB Housing:1` |
| Component name | PCB Housing |
| Depth | 1 |
| Path segments | base_link → PCB_Housing |
| Parent path | `base_link:1` |
| Child occurrences | 3 |
| **Transforms** | |
| Global position (m) | (-0.000414, -0.174060, -0.006260) |
| Global position (mm) | (-0.41, -174.06, -6.26) |
| Local transform (m) | (-0.000414, -0.174060, -0.006260) |
| Assembly context depth | 1 |
| transform2 (m) | (-0.000414, -0.174060, -0.006260) |

#### 🔧 COMPONENT: `Rear_Base_Plate`

| Property | Value |
|---|---|
| Full path | `base_link:1+Rear_Base_Plate:1` |
| Component name | Rear_Base_Plate |
| Depth | 1 |
| Path segments | base_link → Rear_Base_Plate |
| Parent path | `base_link:1` |
| **Transforms** | |
| Global position (m) | (0.000151, 0.000124, -0.000046) |
| Global position (mm) | (0.15, 0.12, -0.05) |
| Local transform (m) | (0.000151, 0.000124, -0.000046) |
| Assembly context depth | 1 |
| transform2 (m) | (0.000151, 0.000124, -0.000046) |
| **Physical** | |
| Mass | 1.396297 kg (1396.297 g) |
| Volume | 1.778722e-04 m³ |
| Density | 7850.0 kg/m³ |
| Surface area | 7.545173e-02 m² |
| Body count | 1 |
| CoM (component-local, m) | (-0.095749, -0.055476, 0.013007) |
| CoM (global, m) | (-0.095598, -0.055353, 0.012961) |
| CoM (global, mm) | (-95.60, -55.35, 12.96) |
| **Inertia at origin (kg·m²)** | |
| Ixx, Iyy, Izz | 8.328051e-03, 1.701441e-02, 2.486320e-02 |
| Ixy, Ixz, Iyz | -7.575527e-03, 1.735967e-03, 1.015033e-03 |
| **Inertia at CoM (kg·m²)** | |
| Ixx, Iyy, Izz | 3.794528e-03, 3.977072e-03, 7.764790e-03 |
| Ixy, Ixz, Iyz | -1.586404e-04, -2.974878e-06, 7.500591e-06 |
| Bounding box (m) | 0.2301 × 0.2190 × 0.0054 |
| Bounding box (mm) | 230.09 × 219.04 × 5.43 |
| **Material & Appearance** | |
| Material | Steel |
| Appearance | Plastic_Translucent_Glossy_White |
| Color (RGB 0-1) | (1.000, 1.000, 1.000) |
| Color (RGB 0-255) | (255, 255, 255) |

#### 🔧 COMPONENT: `Top_Plate`

| Property | Value |
|---|---|
| Full path | `base_link:1+Top_Plate:1` |
| Component name | Top_Plate |
| Depth | 1 |
| Path segments | base_link → Top_Plate |
| Parent path | `base_link:1` |
| **Transforms** | |
| Global position (m) | (0.000000, 0.000000, 0.000000) |
| Global position (mm) | (0.00, 0.00, 0.00) |
| Local transform (m) | (0.000000, 0.000000, 0.000000) |
| Assembly context depth | 1 |
| transform2 (m) | (0.000000, 0.000000, 0.000000) |
| **Physical** | |
| Mass | 1.175222 kg (1175.222 g) |
| Volume | 1.497098e-04 m³ |
| Density | 7850.0 kg/m³ |
| Surface area | 4.454552e-02 m² |
| Body count | 1 |
| CoM (component-local, m) | (0.000001, -0.000000, 0.375985) |
| CoM (global, m) | (0.000001, -0.000000, 0.375985) |
| CoM (global, mm) | (0.00, -0.00, 375.98) |
| **Inertia at origin (kg·m²)** | |
| Ixx, Iyy, Izz | 1.673064e-01, 1.673064e-01, 2.197908e-03 |
| Ixy, Ixz, Iyz | 2.003029e-08, -2.868358e-07, 4.429116e-08 |
| **Inertia at CoM (kg·m²)** | |
| Ixx, Iyy, Izz | 1.171949e-03, 1.171956e-03, 2.197908e-03 |
| Ixy, Ixz, Iyz | 2.003022e-08, 5.389371e-09, 3.318574e-09 |
| Bounding box (m) | 0.1250 × 0.1256 × 0.0480 |
| Bounding box (mm) | 125.00 × 125.63 × 47.96 |
| **Material & Appearance** | |
| Material | Steel |
| Appearance | ABS_White_1 |
| Color (RGB 0-1) | (0.075, 0.129, 0.502) |
| Color (RGB 0-255) | (19, 33, 128) |

#### 📦 SUBASSEMBLY: `LD19_LiDAR`

| Property | Value |
|---|---|
| Full path | `lidar_link:1+LD19_LiDAR:1` |
| Component name | LD19_LiDAR |
| Depth | 1 |
| Path segments | lidar_link → LD19_LiDAR |
| Parent path | `lidar_link:1` |
| Child occurrences | 8 |
| **Transforms** | |
| Global position (m) | (-0.000000, -0.114885, 0.052899) |
| Global position (mm) | (-0.00, -114.88, 52.90) |
| Local transform (m) | (0.000000, -0.114000, 0.053000) |
| Assembly context depth | 1 |
| transform2 (m) | (-0.000000, -0.114885, 0.052899) |

#### 🔧 COMPONENT: `Lidar_Mounting_Plate`

| Property | Value |
|---|---|
| Full path | `lidar_link:1+Lidar_Mounting_Plate:1` |
| Component name | Lidar_Mounting_Plate |
| Depth | 1 |
| Path segments | lidar_link → Lidar_Mounting_Plate |
| Parent path | `lidar_link:1` |
| **Transforms** | |
| Global position (m) | (-0.000000, -0.114885, 0.024899) |
| Global position (mm) | (-0.00, -114.88, 24.90) |
| Local transform (m) | (0.000000, -0.114000, 0.025000) |
| Assembly context depth | 1 |
| transform2 (m) | (-0.000000, -0.114885, 0.024899) |
| **Physical** | |
| Mass | 0.982919 kg (982.919 g) |
| Volume | 1.252126e-04 m³ |
| Density | 7850.0 kg/m³ |
| Surface area | 4.300812e-02 m² |
| Body count | 1 |
| CoM (component-local, m) | (-0.002818, 0.022250, 0.007150) |
| CoM (global, m) | (-0.002818, -0.092635, 0.032049) |
| CoM (global, mm) | (-2.82, -92.63, 32.05) |
| **Inertia at origin (kg·m²)** | |
| Ixx, Iyy, Izz | 1.895764e-03, 8.237739e-04, 2.361065e-03 |
| Ixy, Ixz, Iyz | 1.545448e-04, 3.345704e-05, -9.451546e-05 |
| **Inertia at CoM (kg·m²)** | |
| Ixx, Iyy, Izz | 1.358920e-03, 7.657179e-04, 1.866666e-03 |
| Ixy, Ixz, Iyz | 9.291505e-05, 1.365196e-05, 6.185419e-05 |
| Bounding box (m) | 0.1095 × 0.1223 × 0.0370 |
| Bounding box (mm) | 109.46 × 122.25 × 37.00 |
| **Material & Appearance** | |
| Material | Steel |
| Appearance | Plastic_Translucent_Glossy_White |
| Color (RGB 0-1) | (1.000, 1.000, 1.000) |
| Color (RGB 0-255) | (255, 255, 255) |

#### 🔧 COMPONENT: `4mm_Rigid_Flange_Coupling`

| Property | Value |
|---|---|
| Full path | `wheel_1_link:1+4mm_Rigid_Flange_Coupling:2` |
| Component name | 4mm_Rigid_Flange_Coupling |
| Depth | 1 |
| Path segments | wheel_1_link → 4mm_Rigid_Flange_Coupling |
| Parent path | `wheel_1_link:1` |
| **Transforms** | |
| Global position (m) | (0.234076, -0.135144, -0.028962) |
| Global position (mm) | (234.08, -135.14, -28.96) |
| Local transform (m) | (0.234076, -0.135144, -0.028962) |
| Assembly context depth | 1 |
| transform2 (m) | (0.234076, -0.135144, -0.028962) |
| **Physical** | |
| Mass | 0.003505 kg (3.505 g) |
| Volume | 1.298066e-06 m³ |
| Density | 2700.0 kg/m³ |
| Surface area | 1.362546e-03 m² |
| Body count | 1 |
| CoM (component-local, m) | (-0.000045, 0.003858, -0.000045) |
| CoM (global, m) | (0.234031, -0.131286, -0.029007) |
| CoM (global, mm) | (234.03, -131.29, -29.01) |
| **Inertia at origin (kg·m²)** | |
| Ixx, Iyy, Izz | 1.676406e-07, 1.384679e-07, 1.676407e-07 |
| Ixy, Ixz, Iyz | 9.406056e-10, -1.798561e-22, 9.406056e-10 |
| **Inertia at CoM (kg·m²)** | |
| Ixx, Iyy, Izz | 1.154665e-07, 1.384538e-07, 1.154665e-07 |
| Ixy, Ixz, Iyz | 3.351199e-10, 7.027657e-12, 3.351199e-10 |
| Bounding box (m) | 0.0220 × 0.0120 × 0.0220 |
| Bounding box (mm) | 22.00 × 12.00 × 22.00 |
| **Material & Appearance** | |
| Material | Aluminum |
| Appearance | Aluminum_Satin |
| Color (RGB 0-1) | (0.961, 0.961, 0.965) |
| Color (RGB 0-255) | (245, 245, 246) |

#### 🔧 COMPONENT: `Omni_Wheel`

| Property | Value |
|---|---|
| Full path | `wheel_1_link:1+Omni_Wheel:1` |
| Component name | Omni_Wheel |
| Depth | 1 |
| Path segments | wheel_1_link → Omni_Wheel |
| Parent path | `wheel_1_link:1` |
| **Transforms** | |
| Global position (m) | (-0.094909, -0.073309, -0.634871) |
| Global position (mm) | (-94.91, -73.31, -634.87) |
| Local transform (m) | (-0.094909, -0.073309, -0.634871) |
| Assembly context depth | 1 |
| transform2 (m) | (-0.094909, -0.073309, -0.634871) |
| **Physical** | |
| Mass | 1.479811 kg (1479.811 g) |
| Volume | 1.885110e-04 m³ |
| Density | 7850.0 kg/m³ |
| Surface area | 9.739809e-02 m² |
| Body count | 60 |
| CoM (component-local, m) | (-0.017319, -0.116331, 0.693024) |
| CoM (global, m) | (-0.112228, -0.189640, 0.058153) |
| CoM (global, mm) | (-112.23, -189.64, 58.15) |
| **Inertia at origin (kg·m²)** | |
| Ixx, Iyy, Izz | 7.324645e-01, 7.122855e-01, 2.176439e-02 |
| Ixy, Ixz, Iyz | -2.974065e-03, 1.743386e-02, 1.192990e-01 |
| **Inertia at CoM (kg·m²)** | |
| Ixx, Iyy, Izz | 1.711535e-03, 1.114997e-03, 1.294264e-03 |
| Ixy, Ixz, Iyz | 7.340579e-06, -3.273397e-04, -3.993264e-06 |
| Bounding box (m) | 0.0766 × 0.1022 × 0.1017 |
| Bounding box (mm) | 76.59 × 102.22 × 101.66 |
| **Material & Appearance** | |
| Material | Steel |
| Appearance | PA_12_Nylon_PA_603_CF_with_EOS_P_3D_Printers |
| Color (RGB 0-1) | (0.373, 0.424, 0.514) |
| Color (RGB 0-255) | (95, 108, 131) |
| **Per-body breakdown** | |
| Body 0: Body1 | mass=166.486g, material=Steel, inertia_src=api |
| Body 1: Body2 | mass=37.373g, material=Steel, inertia_src=api |
| Body 2: Body3 | mass=0.000g, material=Steel, inertia_src=api |
| Body 3: Body4 | mass=1.392g, material=Steel, inertia_src=api |
| Body 4: Body5 | mass=37.373g, material=Steel, inertia_src=api |
| Body 5: Body6 | mass=0.000g, material=Steel, inertia_src=api |
| Body 6: Body7 | mass=1.392g, material=Steel, inertia_src=api |
| Body 7: Body8 | mass=37.373g, material=Steel, inertia_src=api |
| Body 8: Body9 | mass=0.000g, material=Steel, inertia_src=api |
| Body 9: Body10 | mass=1.392g, material=Steel, inertia_src=api |
| Body 10: Body11 | mass=37.373g, material=Steel, inertia_src=api |
| Body 11: Body12 | mass=0.000g, material=Steel, inertia_src=api |
| Body 12: Body13 | mass=1.392g, material=Steel, inertia_src=api |
| Body 13: Body14 | mass=37.373g, material=Steel, inertia_src=api |
| Body 14: Body15 | mass=0.000g, material=Steel, inertia_src=api |
| Body 15: Body16 | mass=1.392g, material=Steel, inertia_src=api |
| Body 16: Body17 | mass=37.373g, material=Steel, inertia_src=api |
| Body 17: Body18 | mass=0.000g, material=Steel, inertia_src=api |
| Body 18: Body19 | mass=1.392g, material=Steel, inertia_src=api |
| Body 19: Body20 | mass=37.373g, material=Steel, inertia_src=api |
| Body 20: Body21 | mass=0.000g, material=Steel, inertia_src=api |
| Body 21: Body22 | mass=1.392g, material=Steel, inertia_src=api |
| Body 22: Body23 | mass=37.373g, material=Steel, inertia_src=api |
| Body 23: Body24 | mass=0.000g, material=Steel, inertia_src=api |
| Body 24: Body25 | mass=1.392g, material=Steel, inertia_src=api |
| Body 25: Body26 | mass=37.373g, material=Steel, inertia_src=api |
| Body 26: Body27 | mass=0.000g, material=Steel, inertia_src=api |
| Body 27: Body28 | mass=1.392g, material=Steel, inertia_src=api |
| Body 28: Body29 | mass=166.488g, material=Steel, inertia_src=api |
| Body 29: Body30 | mass=97.317g, material=Steel, inertia_src=api |
| Body 30: Body31 | mass=166.486g, material=Steel, inertia_src=api |
| Body 31: Body32 | mass=37.373g, material=Steel, inertia_src=api |
| Body 32: Body33 | mass=0.000g, material=Steel, inertia_src=api |
| Body 33: Body34 | mass=1.392g, material=Steel, inertia_src=api |
| Body 34: Body35 | mass=37.373g, material=Steel, inertia_src=api |
| Body 35: Body36 | mass=0.000g, material=Steel, inertia_src=api |
| Body 36: Body37 | mass=1.392g, material=Steel, inertia_src=api |
| Body 37: Body38 | mass=37.373g, material=Steel, inertia_src=api |
| Body 38: Body39 | mass=0.000g, material=Steel, inertia_src=api |
| Body 39: Body40 | mass=1.392g, material=Steel, inertia_src=api |
| Body 40: Body41 | mass=37.373g, material=Steel, inertia_src=api |
| Body 41: Body42 | mass=0.000g, material=Steel, inertia_src=api |
| Body 42: Body43 | mass=1.392g, material=Steel, inertia_src=api |
| Body 43: Body44 | mass=37.373g, material=Steel, inertia_src=api |
| Body 44: Body45 | mass=0.000g, material=Steel, inertia_src=api |
| Body 45: Body46 | mass=1.392g, material=Steel, inertia_src=api |
| Body 46: Body47 | mass=37.373g, material=Steel, inertia_src=api |
| Body 47: Body48 | mass=0.000g, material=Steel, inertia_src=api |
| Body 48: Body49 | mass=1.392g, material=Steel, inertia_src=api |
| Body 49: Body50 | mass=37.373g, material=Steel, inertia_src=api |
| Body 50: Body51 | mass=0.000g, material=Steel, inertia_src=api |
| Body 51: Body52 | mass=1.392g, material=Steel, inertia_src=api |
| Body 52: Body53 | mass=37.373g, material=Steel, inertia_src=api |
| Body 53: Body54 | mass=0.000g, material=Steel, inertia_src=api |
| Body 54: Body55 | mass=1.392g, material=Steel, inertia_src=api |
| Body 55: Body56 | mass=37.373g, material=Steel, inertia_src=api |
| Body 56: Body57 | mass=0.000g, material=Steel, inertia_src=api |
| Body 57: Body58 | mass=1.392g, material=Steel, inertia_src=api |
| Body 58: Body59 | mass=166.484g, material=Steel, inertia_src=api |
| Body 59: Body60 | mass=18.785g, material=Steel, inertia_src=api |

#### 📦 SUBASSEMBLY: `Wheel_Hub`

| Property | Value |
|---|---|
| Full path | `wheel_1_link:1+Wheel_Hub:2` |
| Component name | Wheel_Hub |
| Depth | 1 |
| Path segments | wheel_1_link → Wheel_Hub |
| Parent path | `wheel_1_link:1` |
| Child occurrences | 2 |
| **Transforms** | |
| Global position (m) | (0.234076, -0.135144, -0.028962) |
| Global position (mm) | (234.08, -135.14, -28.96) |
| Local transform (m) | (0.234076, -0.135144, -0.028962) |
| Assembly context depth | 1 |
| transform2 (m) | (0.234076, -0.135144, -0.028962) |

#### 🔧 COMPONENT: `4mm_Rigid_Flange_Coupling`

| Property | Value |
|---|---|
| Full path | `wheel_2_link:1+4mm_Rigid_Flange_Coupling:3` |
| Component name | 4mm_Rigid_Flange_Coupling |
| Depth | 1 |
| Path segments | wheel_2_link → 4mm_Rigid_Flange_Coupling |
| Parent path | `wheel_2_link:1` |
| **Transforms** | |
| Global position (m) | (-0.000000, 0.270287, -0.028962) |
| Global position (mm) | (-0.00, 270.29, -28.96) |
| Local transform (m) | (-0.000000, 0.270287, -0.028962) |
| Assembly context depth | 1 |
| transform2 (m) | (-0.000000, 0.270287, -0.028962) |
| **Physical** | |
| Mass | 0.003505 kg (3.505 g) |
| Volume | 1.298066e-06 m³ |
| Density | 2700.0 kg/m³ |
| Surface area | 1.362546e-03 m² |
| Body count | 1 |
| CoM (component-local, m) | (-0.000045, 0.003858, -0.000045) |
| CoM (global, m) | (-0.000045, 0.274145, -0.029007) |
| CoM (global, mm) | (-0.04, 274.15, -29.01) |
| **Inertia at origin (kg·m²)** | |
| Ixx, Iyy, Izz | 1.676406e-07, 1.384679e-07, 1.676407e-07 |
| Ixy, Ixz, Iyz | 9.406056e-10, -1.798561e-22, 9.406056e-10 |
| **Inertia at CoM (kg·m²)** | |
| Ixx, Iyy, Izz | 1.154665e-07, 1.384538e-07, 1.154665e-07 |
| Ixy, Ixz, Iyz | 3.351199e-10, 7.027657e-12, 3.351199e-10 |
| Bounding box (m) | 0.0220 × 0.0120 × 0.0220 |
| Bounding box (mm) | 22.00 × 12.00 × 22.00 |
| **Material & Appearance** | |
| Material | Aluminum |
| Appearance | Aluminum_Satin |
| Color (RGB 0-1) | (0.961, 0.961, 0.965) |
| Color (RGB 0-255) | (245, 245, 246) |

#### 🔧 COMPONENT: `Omni_Wheel`

| Property | Value |
|---|---|
| Full path | `wheel_2_link:1+Omni_Wheel:3` |
| Component name | Omni_Wheel |
| Depth | 1 |
| Path segments | wheel_2_link → Omni_Wheel |
| Parent path | `wheel_2_link:1` |
| **Transforms** | |
| Global position (m) | (0.132999, -0.053696, -0.625992) |
| Global position (mm) | (133.00, -53.70, -625.99) |
| Local transform (m) | (0.132999, -0.053696, -0.625992) |
| Assembly context depth | 1 |
| transform2 (m) | (0.132999, -0.053696, -0.625992) |
| **Physical** | |
| Mass | 1.479811 kg (1479.811 g) |
| Volume | 1.885110e-04 m³ |
| Density | 7850.0 kg/m³ |
| Surface area | 9.739809e-02 m² |
| Body count | 60 |
| CoM (component-local, m) | (-0.017319, -0.116331, 0.693024) |
| CoM (global, m) | (0.115680, -0.170027, 0.067032) |
| CoM (global, mm) | (115.68, -170.03, 67.03) |
| **Inertia at origin (kg·m²)** | |
| Ixx, Iyy, Izz | 7.324645e-01, 7.122855e-01, 2.176439e-02 |
| Ixy, Ixz, Iyz | -2.974065e-03, 1.743386e-02, 1.192990e-01 |
| **Inertia at CoM (kg·m²)** | |
| Ixx, Iyy, Izz | 1.711535e-03, 1.114997e-03, 1.294264e-03 |
| Ixy, Ixz, Iyz | 7.340579e-06, -3.273397e-04, -3.993264e-06 |
| Bounding box (m) | 0.0766 × 0.1022 × 0.1017 |
| Bounding box (mm) | 76.59 × 102.22 × 101.66 |
| **Material & Appearance** | |
| Material | Steel |
| Appearance | PA_12_Nylon_PA_603_CF_with_EOS_P_3D_Printers |
| Color (RGB 0-1) | (0.373, 0.424, 0.514) |
| Color (RGB 0-255) | (95, 108, 131) |
| **Per-body breakdown** | |
| Body 0: Body1 | mass=166.486g, material=Steel, inertia_src=api |
| Body 1: Body2 | mass=37.373g, material=Steel, inertia_src=api |
| Body 2: Body3 | mass=0.000g, material=Steel, inertia_src=api |
| Body 3: Body4 | mass=1.392g, material=Steel, inertia_src=api |
| Body 4: Body5 | mass=37.373g, material=Steel, inertia_src=api |
| Body 5: Body6 | mass=0.000g, material=Steel, inertia_src=api |
| Body 6: Body7 | mass=1.392g, material=Steel, inertia_src=api |
| Body 7: Body8 | mass=37.373g, material=Steel, inertia_src=api |
| Body 8: Body9 | mass=0.000g, material=Steel, inertia_src=api |
| Body 9: Body10 | mass=1.392g, material=Steel, inertia_src=api |
| Body 10: Body11 | mass=37.373g, material=Steel, inertia_src=api |
| Body 11: Body12 | mass=0.000g, material=Steel, inertia_src=api |
| Body 12: Body13 | mass=1.392g, material=Steel, inertia_src=api |
| Body 13: Body14 | mass=37.373g, material=Steel, inertia_src=api |
| Body 14: Body15 | mass=0.000g, material=Steel, inertia_src=api |
| Body 15: Body16 | mass=1.392g, material=Steel, inertia_src=api |
| Body 16: Body17 | mass=37.373g, material=Steel, inertia_src=api |
| Body 17: Body18 | mass=0.000g, material=Steel, inertia_src=api |
| Body 18: Body19 | mass=1.392g, material=Steel, inertia_src=api |
| Body 19: Body20 | mass=37.373g, material=Steel, inertia_src=api |
| Body 20: Body21 | mass=0.000g, material=Steel, inertia_src=api |
| Body 21: Body22 | mass=1.392g, material=Steel, inertia_src=api |
| Body 22: Body23 | mass=37.373g, material=Steel, inertia_src=api |
| Body 23: Body24 | mass=0.000g, material=Steel, inertia_src=api |
| Body 24: Body25 | mass=1.392g, material=Steel, inertia_src=api |
| Body 25: Body26 | mass=37.373g, material=Steel, inertia_src=api |
| Body 26: Body27 | mass=0.000g, material=Steel, inertia_src=api |
| Body 27: Body28 | mass=1.392g, material=Steel, inertia_src=api |
| Body 28: Body29 | mass=166.488g, material=Steel, inertia_src=api |
| Body 29: Body30 | mass=97.317g, material=Steel, inertia_src=api |
| Body 30: Body31 | mass=166.486g, material=Steel, inertia_src=api |
| Body 31: Body32 | mass=37.373g, material=Steel, inertia_src=api |
| Body 32: Body33 | mass=0.000g, material=Steel, inertia_src=api |
| Body 33: Body34 | mass=1.392g, material=Steel, inertia_src=api |
| Body 34: Body35 | mass=37.373g, material=Steel, inertia_src=api |
| Body 35: Body36 | mass=0.000g, material=Steel, inertia_src=api |
| Body 36: Body37 | mass=1.392g, material=Steel, inertia_src=api |
| Body 37: Body38 | mass=37.373g, material=Steel, inertia_src=api |
| Body 38: Body39 | mass=0.000g, material=Steel, inertia_src=api |
| Body 39: Body40 | mass=1.392g, material=Steel, inertia_src=api |
| Body 40: Body41 | mass=37.373g, material=Steel, inertia_src=api |
| Body 41: Body42 | mass=0.000g, material=Steel, inertia_src=api |
| Body 42: Body43 | mass=1.392g, material=Steel, inertia_src=api |
| Body 43: Body44 | mass=37.373g, material=Steel, inertia_src=api |
| Body 44: Body45 | mass=0.000g, material=Steel, inertia_src=api |
| Body 45: Body46 | mass=1.392g, material=Steel, inertia_src=api |
| Body 46: Body47 | mass=37.373g, material=Steel, inertia_src=api |
| Body 47: Body48 | mass=0.000g, material=Steel, inertia_src=api |
| Body 48: Body49 | mass=1.392g, material=Steel, inertia_src=api |
| Body 49: Body50 | mass=37.373g, material=Steel, inertia_src=api |
| Body 50: Body51 | mass=0.000g, material=Steel, inertia_src=api |
| Body 51: Body52 | mass=1.392g, material=Steel, inertia_src=api |
| Body 52: Body53 | mass=37.373g, material=Steel, inertia_src=api |
| Body 53: Body54 | mass=0.000g, material=Steel, inertia_src=api |
| Body 54: Body55 | mass=1.392g, material=Steel, inertia_src=api |
| Body 55: Body56 | mass=37.373g, material=Steel, inertia_src=api |
| Body 56: Body57 | mass=0.000g, material=Steel, inertia_src=api |
| Body 57: Body58 | mass=1.392g, material=Steel, inertia_src=api |
| Body 58: Body59 | mass=166.484g, material=Steel, inertia_src=api |
| Body 59: Body60 | mass=18.785g, material=Steel, inertia_src=api |

#### 📦 SUBASSEMBLY: `Wheel_Hub`

| Property | Value |
|---|---|
| Full path | `wheel_2_link:1+Wheel_Hub:3` |
| Component name | Wheel_Hub |
| Depth | 1 |
| Path segments | wheel_2_link → Wheel_Hub |
| Parent path | `wheel_2_link:1` |
| Child occurrences | 2 |
| **Transforms** | |
| Global position (m) | (-0.000000, 0.270287, -0.028962) |
| Global position (mm) | (-0.00, 270.29, -28.96) |
| Local transform (m) | (-0.000000, 0.270287, -0.028962) |
| Assembly context depth | 1 |
| transform2 (m) | (-0.000000, 0.270287, -0.028962) |

#### 🔧 COMPONENT: `4mm_Rigid_Flange_Coupling`

| Property | Value |
|---|---|
| Full path | `wheel_3_link:1+4mm_Rigid_Flange_Coupling:1` |
| Component name | 4mm_Rigid_Flange_Coupling |
| Depth | 1 |
| Path segments | wheel_3_link → 4mm_Rigid_Flange_Coupling |
| Parent path | `wheel_3_link:1` |
| **Transforms** | |
| Global position (m) | (-0.234076, -0.135144, -0.028962) |
| Global position (mm) | (-234.08, -135.14, -28.96) |
| Local transform (m) | (-0.234076, -0.135144, -0.028962) |
| Assembly context depth | 1 |
| transform2 (m) | (-0.234076, -0.135144, -0.028962) |
| **Physical** | |
| Mass | 0.003505 kg (3.505 g) |
| Volume | 1.298066e-06 m³ |
| Density | 2700.0 kg/m³ |
| Surface area | 1.362546e-03 m² |
| Body count | 1 |
| CoM (component-local, m) | (-0.000045, 0.003858, -0.000045) |
| CoM (global, m) | (-0.234121, -0.131286, -0.029007) |
| CoM (global, mm) | (-234.12, -131.29, -29.01) |
| **Inertia at origin (kg·m²)** | |
| Ixx, Iyy, Izz | 1.676406e-07, 1.384679e-07, 1.676407e-07 |
| Ixy, Ixz, Iyz | 9.406056e-10, -1.798561e-22, 9.406056e-10 |
| **Inertia at CoM (kg·m²)** | |
| Ixx, Iyy, Izz | 1.154665e-07, 1.384538e-07, 1.154665e-07 |
| Ixy, Ixz, Iyz | 3.351199e-10, 7.027657e-12, 3.351199e-10 |
| Bounding box (m) | 0.0220 × 0.0120 × 0.0220 |
| Bounding box (mm) | 22.00 × 12.00 × 22.00 |
| **Material & Appearance** | |
| Material | Aluminum |
| Appearance | Aluminum_Satin |
| Color (RGB 0-1) | (0.961, 0.961, 0.965) |
| Color (RGB 0-255) | (245, 245, 246) |

#### 🔧 COMPONENT: `Omni_Wheel`

| Property | Value |
|---|---|
| Full path | `wheel_3_link:1+Omni_Wheel:2` |
| Component name | Omni_Wheel |
| Depth | 1 |
| Path segments | wheel_3_link → Omni_Wheel |
| Parent path | `wheel_3_link:1` |
| **Transforms** | |
| Global position (m) | (0.001943, 0.133940, -0.621278) |
| Global position (mm) | (1.94, 133.94, -621.28) |
| Local transform (m) | (0.001943, 0.133940, -0.621278) |
| Assembly context depth | 1 |
| transform2 (m) | (0.001943, 0.133940, -0.621278) |
| **Physical** | |
| Mass | 1.479811 kg (1479.811 g) |
| Volume | 1.885110e-04 m³ |
| Density | 7850.0 kg/m³ |
| Surface area | 9.739809e-02 m² |
| Body count | 60 |
| CoM (component-local, m) | (-0.017319, -0.116331, 0.693024) |
| CoM (global, m) | (-0.015376, 0.017609, 0.071746) |
| CoM (global, mm) | (-15.38, 17.61, 71.75) |
| **Inertia at origin (kg·m²)** | |
| Ixx, Iyy, Izz | 7.324645e-01, 7.122855e-01, 2.176439e-02 |
| Ixy, Ixz, Iyz | -2.974065e-03, 1.743386e-02, 1.192990e-01 |
| **Inertia at CoM (kg·m²)** | |
| Ixx, Iyy, Izz | 1.711535e-03, 1.114997e-03, 1.294264e-03 |
| Ixy, Ixz, Iyz | 7.340579e-06, -3.273397e-04, -3.993264e-06 |
| Bounding box (m) | 0.0766 × 0.1022 × 0.1017 |
| Bounding box (mm) | 76.59 × 102.22 × 101.66 |
| **Material & Appearance** | |
| Material | Steel |
| Appearance | PA_12_Nylon_PA_603_CF_with_EOS_P_3D_Printers |
| Color (RGB 0-1) | (0.373, 0.424, 0.514) |
| Color (RGB 0-255) | (95, 108, 131) |
| **Per-body breakdown** | |
| Body 0: Body1 | mass=166.486g, material=Steel, inertia_src=api |
| Body 1: Body2 | mass=37.373g, material=Steel, inertia_src=api |
| Body 2: Body3 | mass=0.000g, material=Steel, inertia_src=api |
| Body 3: Body4 | mass=1.392g, material=Steel, inertia_src=api |
| Body 4: Body5 | mass=37.373g, material=Steel, inertia_src=api |
| Body 5: Body6 | mass=0.000g, material=Steel, inertia_src=api |
| Body 6: Body7 | mass=1.392g, material=Steel, inertia_src=api |
| Body 7: Body8 | mass=37.373g, material=Steel, inertia_src=api |
| Body 8: Body9 | mass=0.000g, material=Steel, inertia_src=api |
| Body 9: Body10 | mass=1.392g, material=Steel, inertia_src=api |
| Body 10: Body11 | mass=37.373g, material=Steel, inertia_src=api |
| Body 11: Body12 | mass=0.000g, material=Steel, inertia_src=api |
| Body 12: Body13 | mass=1.392g, material=Steel, inertia_src=api |
| Body 13: Body14 | mass=37.373g, material=Steel, inertia_src=api |
| Body 14: Body15 | mass=0.000g, material=Steel, inertia_src=api |
| Body 15: Body16 | mass=1.392g, material=Steel, inertia_src=api |
| Body 16: Body17 | mass=37.373g, material=Steel, inertia_src=api |
| Body 17: Body18 | mass=0.000g, material=Steel, inertia_src=api |
| Body 18: Body19 | mass=1.392g, material=Steel, inertia_src=api |
| Body 19: Body20 | mass=37.373g, material=Steel, inertia_src=api |
| Body 20: Body21 | mass=0.000g, material=Steel, inertia_src=api |
| Body 21: Body22 | mass=1.392g, material=Steel, inertia_src=api |
| Body 22: Body23 | mass=37.373g, material=Steel, inertia_src=api |
| Body 23: Body24 | mass=0.000g, material=Steel, inertia_src=api |
| Body 24: Body25 | mass=1.392g, material=Steel, inertia_src=api |
| Body 25: Body26 | mass=37.373g, material=Steel, inertia_src=api |
| Body 26: Body27 | mass=0.000g, material=Steel, inertia_src=api |
| Body 27: Body28 | mass=1.392g, material=Steel, inertia_src=api |
| Body 28: Body29 | mass=166.488g, material=Steel, inertia_src=api |
| Body 29: Body30 | mass=97.317g, material=Steel, inertia_src=api |
| Body 30: Body31 | mass=166.486g, material=Steel, inertia_src=api |
| Body 31: Body32 | mass=37.373g, material=Steel, inertia_src=api |
| Body 32: Body33 | mass=0.000g, material=Steel, inertia_src=api |
| Body 33: Body34 | mass=1.392g, material=Steel, inertia_src=api |
| Body 34: Body35 | mass=37.373g, material=Steel, inertia_src=api |
| Body 35: Body36 | mass=0.000g, material=Steel, inertia_src=api |
| Body 36: Body37 | mass=1.392g, material=Steel, inertia_src=api |
| Body 37: Body38 | mass=37.373g, material=Steel, inertia_src=api |
| Body 38: Body39 | mass=0.000g, material=Steel, inertia_src=api |
| Body 39: Body40 | mass=1.392g, material=Steel, inertia_src=api |
| Body 40: Body41 | mass=37.373g, material=Steel, inertia_src=api |
| Body 41: Body42 | mass=0.000g, material=Steel, inertia_src=api |
| Body 42: Body43 | mass=1.392g, material=Steel, inertia_src=api |
| Body 43: Body44 | mass=37.373g, material=Steel, inertia_src=api |
| Body 44: Body45 | mass=0.000g, material=Steel, inertia_src=api |
| Body 45: Body46 | mass=1.392g, material=Steel, inertia_src=api |
| Body 46: Body47 | mass=37.373g, material=Steel, inertia_src=api |
| Body 47: Body48 | mass=0.000g, material=Steel, inertia_src=api |
| Body 48: Body49 | mass=1.392g, material=Steel, inertia_src=api |
| Body 49: Body50 | mass=37.373g, material=Steel, inertia_src=api |
| Body 50: Body51 | mass=0.000g, material=Steel, inertia_src=api |
| Body 51: Body52 | mass=1.392g, material=Steel, inertia_src=api |
| Body 52: Body53 | mass=37.373g, material=Steel, inertia_src=api |
| Body 53: Body54 | mass=0.000g, material=Steel, inertia_src=api |
| Body 54: Body55 | mass=1.392g, material=Steel, inertia_src=api |
| Body 55: Body56 | mass=37.373g, material=Steel, inertia_src=api |
| Body 56: Body57 | mass=0.000g, material=Steel, inertia_src=api |
| Body 57: Body58 | mass=1.392g, material=Steel, inertia_src=api |
| Body 58: Body59 | mass=166.484g, material=Steel, inertia_src=api |
| Body 59: Body60 | mass=18.785g, material=Steel, inertia_src=api |

#### 📦 SUBASSEMBLY: `Wheel_Hub`

| Property | Value |
|---|---|
| Full path | `wheel_3_link:1+Wheel_Hub:1` |
| Component name | Wheel_Hub |
| Depth | 1 |
| Path segments | wheel_3_link → Wheel_Hub |
| Parent path | `wheel_3_link:1` |
| Child occurrences | 2 |
| **Transforms** | |
| Global position (m) | (-0.234076, -0.135144, -0.028962) |
| Global position (mm) | (-234.08, -135.14, -28.96) |
| Local transform (m) | (-0.234076, -0.135144, -0.028962) |
| Assembly context depth | 1 |
| transform2 (m) | (-0.234076, -0.135144, -0.028962) |

### Depth 2

#### 🔧 COMPONENT: `Battery_Mount_Back`

| Property | Value |
|---|---|
| Full path | `base_link:1+Battery_Mount_Assembly:1+Battery_Mount_Back:1` |
| Component name | Battery_Mount_Back |
| Depth | 2 |
| Path segments | base_link → Battery_Mount_Assembly → Battery_Mount_Back |
| Parent path | `base_link:1+Battery_Mount_Assembly:1` |
| **Transforms** | |
| Global position (m) | (-0.125000, -0.080000, -0.020750) |
| Global position (mm) | (-125.00, -80.00, -20.75) |
| Local transform (m) | (0.000000, 0.055000, 0.000000) |
| Assembly context depth | 2 |
| transform2 (m) | (-0.125000, -0.080000, -0.020750) |
| **Physical** | |
| Mass | 0.155165 kg (155.165 g) |
| Volume | 1.976627e-05 m³ |
| Density | 7850.0 kg/m³ |
| Surface area | 1.054057e-02 m² |
| Body count | 1 |
| CoM (component-local, m) | (0.000000, 0.013619, 0.011160) |
| CoM (global, m) | (-0.125000, -0.066381, -0.009590) |
| CoM (global, mm) | (-125.00, -66.38, -9.59) |
| **Inertia at origin (kg·m²)** | |
| Ixx, Iyy, Izz | 7.929481e-05, 1.133706e-04, 1.076353e-04 |
| Ixy, Ixz, Iyz | -4.261409e-18, -1.200334e-17, -2.501932e-05 |
| **Inertia at CoM (kg·m²)** | |
| Ixx, Iyy, Izz | 3.118676e-05, 9.404404e-05, 7.885380e-05 |
| Ixy, Ixz, Iyz | 1.496812e-18, -7.284783e-18, -1.434422e-06 |
| Bounding box (m) | 0.0750 × 0.0230 × 0.0360 |
| Bounding box (mm) | 75.00 × 23.00 × 36.00 |
| **Material & Appearance** | |
| Material | Steel |
| Appearance | Steel_Satin |
| Color (RGB 0-1) | (0.627, 0.627, 0.627) |
| Color (RGB 0-255) | (160, 160, 160) |

#### 🔧 COMPONENT: `Battery_Mount_Front`

| Property | Value |
|---|---|
| Full path | `base_link:1+Battery_Mount_Assembly:1+Battery_Mount_Front:1` |
| Component name | Battery_Mount_Front |
| Depth | 2 |
| Path segments | base_link → Battery_Mount_Assembly → Battery_Mount_Front |
| Parent path | `base_link:1+Battery_Mount_Assembly:1` |
| **Transforms** | |
| Global position (m) | (-0.070000, -0.080000, -0.020750) |
| Global position (mm) | (-70.00, -80.00, -20.75) |
| Local transform (m) | (0.000000, 0.000000, 0.000000) |
| Assembly context depth | 2 |
| transform2 (m) | (-0.070000, -0.080000, -0.020750) |
| **Physical** | |
| Mass | 0.106316 kg (106.316 g) |
| Volume | 1.354344e-05 m³ |
| Density | 7850.0 kg/m³ |
| Surface area | 7.108607e-03 m² |
| Body count | 1 |
| CoM (component-local, m) | (0.000000, 0.010000, 0.009985) |
| CoM (global, m) | (-0.070000, -0.070000, -0.010765) |
| CoM (global, mm) | (-70.00, -70.00, -10.77) |
| **Inertia at origin (kg·m²)** | |
| Ixx, Iyy, Izz | 4.194555e-05, 8.455186e-05, 7.094471e-05 |
| Ixy, Ixz, Iyz | -4.216787e-18, -1.200334e-17, -1.061565e-05 |
| **Inertia at CoM (kg·m²)** | |
| Ixx, Iyy, Izz | 2.071423e-05, 7.395215e-05, 6.031311e-05 |
| Ixy, Ixz, Iyz | -7.703720e-34, -7.792882e-18, -3.388132e-21 |
| Bounding box (m) | 0.0750 × 0.0200 × 0.0360 |
| Bounding box (mm) | 75.00 × 20.00 × 36.00 |
| **Material & Appearance** | |
| Material | Steel |
| Appearance | Steel_Satin |
| Color (RGB 0-1) | (0.627, 0.627, 0.627) |
| Color (RGB 0-255) | (160, 160, 160) |

#### 📦 SUBASSEMBLY: `Main_PCB`

| Property | Value |
|---|---|
| Full path | `base_link:1+PCB Housing:1+Main_PCB:1` |
| Component name | Main_PCB |
| Depth | 2 |
| Path segments | base_link → PCB_Housing → Main_PCB |
| Parent path | `base_link:1+PCB Housing:1` |
| Child occurrences | 5 |
| **Transforms** | |
| Global position (m) | (-0.000414, -0.174060, -0.006260) |
| Global position (mm) | (-0.41, -174.06, -6.26) |
| Local transform (m) | (0.000000, 0.000000, 0.000000) |
| Assembly context depth | 2 |
| transform2 (m) | (-0.000414, -0.174060, -0.006260) |

#### 🔧 COMPONENT: `PCBoutline`

| Property | Value |
|---|---|
| Full path | `base_link:1+PCB Housing:1+PCBoutline:1` |
| Component name | PCBoutline |
| Depth | 2 |
| Path segments | base_link → PCB_Housing → PCBoutline |
| Parent path | `base_link:1+PCB Housing:1` |
| **Transforms** | |
| Global position (m) | (-0.000414, -0.174060, -0.006260) |
| Global position (mm) | (-0.41, -174.06, -6.26) |
| Local transform (m) | (0.000000, 0.000000, 0.000000) |
| Assembly context depth | 2 |
| transform2 (m) | (-0.000414, -0.174060, -0.006260) |
| **Physical** | |
| Mass | 0.063805 kg (63.805 g) |
| Volume | 8.128066e-06 m³ |
| Density | 7850.0 kg/m³ |
| Surface area | 1.684533e-02 m² |
| Body count | 1 |
| CoM (component-local, m) | (0.150576, -0.096443, -0.000501) |
| CoM (global, m) | (0.150162, -0.270503, -0.006761) |
| CoM (global, mm) | (150.16, -270.50, -6.76) |
| **Inertia at origin (kg·m²)** | |
| Ixx, Iyy, Izz | 6.576142e-04, 1.504544e-03, 2.162115e-03 |
| Ixy, Ixz, Iyz | 9.266062e-04, 4.808828e-06, -3.080068e-06 |
| **Inertia at CoM (kg·m²)** | |
| Ixx, Iyy, Izz | 6.412536e-05, 5.785932e-05, 1.219740e-04 |
| Ixy, Ixz, Iyz | 2.192195e-08, -9.173724e-12, -3.072948e-11 |
| Bounding box (m) | 0.1436 × 0.1259 × 0.0010 |
| Bounding box (mm) | 143.57 × 125.85 × 1.00 |
| **Material & Appearance** | |
| Material | Steel |
| Appearance | Steel_Satin |
| Color (RGB 0-1) | (0.627, 0.627, 0.627) |
| Color (RGB 0-255) | (160, 160, 160) |

#### 🔧 COMPONENT: `PCM_Mounting_Enclosure`

| Property | Value |
|---|---|
| Full path | `base_link:1+PCB Housing:1+PCM_Mounting_Enclosure:1` |
| Component name | PCM_Mounting_Enclosure |
| Depth | 2 |
| Path segments | base_link → PCB_Housing → PCM_Mounting_Enclosure |
| Parent path | `base_link:1+PCB Housing:1` |
| **Transforms** | |
| Global position (m) | (-0.000414, -0.174060, -0.006260) |
| Global position (mm) | (-0.41, -174.06, -6.26) |
| Local transform (m) | (0.000000, 0.000000, 0.000000) |
| Assembly context depth | 2 |
| transform2 (m) | (-0.000414, -0.174060, -0.006260) |
| **Physical** | |
| Mass | 0.540107 kg (540.107 g) |
| Volume | 6.880344e-05 m³ |
| Density | 7850.0 kg/m³ |
| Surface area | 4.512528e-02 m² |
| Body count | 1 |
| CoM (component-local, m) | (0.151014, -0.097435, 0.004104) |
| CoM (global, m) | (0.150600, -0.271494, -0.002156) |
| CoM (global, mm) | (150.60, -271.49, -2.16) |
| **Inertia at origin (kg·m²)** | |
| Ixx, Iyy, Izz | 6.091189e-03, 1.326292e-02, 1.928943e-02 |
| Ixy, Ixz, Iyz | 7.944123e-03, -3.368426e-04, 2.174231e-04 |
| **Inertia at CoM (kg·m²)** | |
| Ixx, Iyy, Izz | 9.545625e-04, 9.365158e-04, 1.844596e-03 |
| Ixy, Ixz, Iyz | -3.034205e-06, -2.078825e-06, 1.432557e-06 |
| Bounding box (m) | 0.1601 × 0.1404 × 0.0215 |
| Bounding box (mm) | 160.06 × 140.44 × 21.51 |
| **Material & Appearance** | |
| Material | Steel |
| Appearance | Steel_Satin |
| Color (RGB 0-1) | (0.627, 0.627, 0.627) |
| Color (RGB 0-255) | (160, 160, 160) |

#### 🔧 COMPONENT: `LD19_PCB`

| Property | Value |
|---|---|
| Full path | `lidar_link:1+LD19_LiDAR:1+LD19_PCB:1` |
| Component name | LD19_PCB |
| Depth | 2 |
| Path segments | lidar_link → LD19_LiDAR → LD19_PCB |
| Parent path | `lidar_link:1+LD19_LiDAR:1` |
| **Transforms** | |
| Global position (m) | (-0.000000, -0.114885, 0.062899) |
| Global position (mm) | (-0.00, -114.88, 62.90) |
| Local transform (m) | (0.000000, 0.000000, 0.010000) |
| Assembly context depth | 2 |
| transform2 (m) | (-0.000000, -0.114885, 0.062899) |
| **Physical** | |
| Mass | 0.008807 kg (8.807 g) |
| Volume | 1.121947e-06 m³ |
| Density | 7850.0 kg/m³ |
| Surface area | 2.545715e-03 m² |
| Body count | 1 |
| CoM (component-local, m) | (-0.001796, 0.000578, -0.006761) |
| CoM (global, m) | (-0.001796, -0.114306, 0.056138) |
| CoM (global, mm) | (-1.80, -114.31, 56.14) |
| **Inertia at origin (kg·m²)** | |
| Ixx, Iyy, Izz | 1.290524e-06, 1.160815e-06, 1.625402e-06 |
| Ixy, Ixz, Iyz | -1.833362e-07, -8.824407e-08, 2.105055e-08 |
| **Inertia at CoM (kg·m²)** | |
| Ixx, Iyy, Izz | 8.850219e-07, 7.298409e-07, 1.594041e-06 |
| Ixy, Ixz, Iyz | -1.924834e-07, 1.871044e-08, -1.337817e-08 |
| Bounding box (m) | 0.0335 × 0.0348 × 0.0048 |
| Bounding box (mm) | 33.50 × 34.80 × 4.80 |
| **Material & Appearance** | |
| Material | Steel |
| Appearance | Opaque_60_204_44 |
| Color (RGB 0-1) | (0.235, 0.800, 0.173) |
| Color (RGB 0-255) | (60, 204, 44) |

#### 🔧 COMPONENT: `LD19_bottom`

| Property | Value |
|---|---|
| Full path | `lidar_link:1+LD19_LiDAR:1+LD19_bottom:1` |
| Component name | LD19_bottom |
| Depth | 2 |
| Path segments | lidar_link → LD19_LiDAR → LD19_bottom |
| Parent path | `lidar_link:1+LD19_LiDAR:1` |
| **Transforms** | |
| Global position (m) | (-0.000000, -0.114885, 0.062899) |
| Global position (mm) | (-0.00, -114.88, 62.90) |
| Local transform (m) | (0.000000, 0.000000, 0.010000) |
| Assembly context depth | 2 |
| transform2 (m) | (-0.000000, -0.114885, 0.062899) |
| **Physical** | |
| Mass | 0.022787 kg (22.787 g) |
| Volume | 2.902742e-06 m³ |
| Density | 7850.0 kg/m³ |
| Surface area | 4.447995e-03 m² |
| Body count | 1 |
| CoM (component-local, m) | (0.000051, -0.000205, -0.008680) |
| CoM (global, m) | (0.000051, -0.115090, 0.054219) |
| CoM (global, mm) | (0.05, -115.09, 54.22) |
| **Inertia at origin (kg·m²)** | |
| Ixx, Iyy, Izz | 5.085686e-06, 5.447590e-06, 6.887465e-06 |
| Ixy, Ixz, Iyz | 3.675303e-07, 8.088302e-09, -4.092655e-08 |
| **Inertia at CoM (kg·m²)** | |
| Ixx, Iyy, Izz | 3.368011e-06, 3.730818e-06, 6.886445e-06 |
| Ixy, Ixz, Iyz | 3.672920e-07, -1.982410e-09, -2.991975e-10 |
| Bounding box (m) | 0.0540 × 0.0463 × 0.0132 |
| Bounding box (mm) | 54.00 × 46.29 × 13.20 |
| **Material & Appearance** | |
| Material | Steel |
| Appearance | Opaque_30_27_54 |
| Color (RGB 0-1) | (0.118, 0.106, 0.212) |
| Color (RGB 0-255) | (30, 27, 54) |

#### 🔧 COMPONENT: `LD19_middle`

| Property | Value |
|---|---|
| Full path | `lidar_link:1+LD19_LiDAR:1+LD19_middle:1` |
| Component name | LD19_middle |
| Depth | 2 |
| Path segments | lidar_link → LD19_LiDAR → LD19_middle |
| Parent path | `lidar_link:1+LD19_LiDAR:1` |
| **Transforms** | |
| Global position (m) | (-0.000000, -0.114885, 0.062899) |
| Global position (mm) | (-0.00, -114.88, 62.90) |
| Local transform (m) | (0.000000, 0.000000, 0.010000) |
| Assembly context depth | 2 |
| transform2 (m) | (-0.000000, -0.114885, 0.062899) |
| **Physical** | |
| Mass | 0.051245 kg (51.245 g) |
| Volume | 6.528012e-06 m³ |
| Density | 7850.0 kg/m³ |
| Surface area | 1.024179e-02 m² |
| Body count | 1 |
| CoM (component-local, m) | (0.000116, -0.000092, -0.000338) |
| CoM (global, m) | (0.000116, -0.114977, 0.062561) |
| CoM (global, mm) | (0.12, -114.98, 62.56) |
| **Inertia at origin (kg·m²)** | |
| Ixx, Iyy, Izz | 9.709253e-06, 9.943172e-06, 1.761794e-05 |
| Ixy, Ixz, Iyz | -2.195598e-07, 3.476397e-08, -4.021915e-08 |
| **Inertia at CoM (kg·m²)** | |
| Ixx, Iyy, Izz | 9.702957e-06, 9.936626e-06, 1.761682e-05 |
| Ixy, Ixz, Iyz | -2.201045e-07, 3.276137e-08, -3.862452e-08 |
| Bounding box (m) | 0.0386 × 0.0386 × 0.0188 |
| Bounding box (mm) | 38.59 × 38.59 × 18.80 |
| **Material & Appearance** | |
| Material | Steel |
| Appearance | Paint_Metallic_Black |
| Color (RGB 0-1) | (0.349, 0.349, 0.349) |
| Color (RGB 0-255) | (89, 89, 89) |

#### 🔧 COMPONENT: `LD19_up`

| Property | Value |
|---|---|
| Full path | `lidar_link:1+LD19_LiDAR:1+LD19_up:1` |
| Component name | LD19_up |
| Depth | 2 |
| Path segments | lidar_link → LD19_LiDAR → LD19_up |
| Parent path | `lidar_link:1+LD19_LiDAR:1` |
| **Transforms** | |
| Global position (m) | (-0.000000, -0.114885, 0.074899) |
| Global position (mm) | (-0.00, -114.88, 74.90) |
| Local transform (m) | (0.000000, 0.000000, 0.022000) |
| Assembly context depth | 2 |
| transform2 (m) | (-0.000000, -0.114885, 0.074899) |
| **Physical** | |
| Mass | 0.019954 kg (19.954 g) |
| Volume | 2.541924e-06 m³ |
| Density | 7850.0 kg/m³ |
| Surface area | 6.565321e-03 m² |
| Body count | 1 |
| CoM (component-local, m) | (-0.000017, -0.000006, 0.004444) |
| CoM (global, m) | (-0.000017, -0.114890, 0.079343) |
| CoM (global, mm) | (-0.02, -114.89, 79.34) |
| **Inertia at origin (kg·m²)** | |
| Ixx, Iyy, Izz | 4.112072e-06, 4.106950e-06, 5.938915e-06 |
| Ixy, Ixz, Iyz | 1.188446e-07, -6.423012e-10, -3.634953e-10 |
| **Inertia at CoM (kg·m²)** | |
| Ixx, Iyy, Izz | 3.717913e-06, 3.712787e-06, 5.938908e-06 |
| Ixy, Ixz, Iyz | 1.188465e-07, -2.119720e-09, -8.854351e-10 |
| Bounding box (m) | 0.0374 × 0.0374 × 0.0202 |
| Bounding box (mm) | 37.36 × 37.36 × 20.20 |
| **Material & Appearance** | |
| Material | Steel |
| Appearance | Opaque_129_129_129 |
| Color (RGB 0-1) | (0.153, 0.153, 0.153) |
| Color (RGB 0-255) | (39, 39, 39) |

#### 🔧 COMPONENT: `PA2X6_1`

| Property | Value |
|---|---|
| Full path | `lidar_link:1+LD19_LiDAR:1+PA2X6_1:1` |
| Component name | PA2X6_1 |
| Depth | 2 |
| Path segments | lidar_link → LD19_LiDAR → PA2X6_1 |
| Parent path | `lidar_link:1+LD19_LiDAR:1` |
| **Transforms** | |
| Global position (m) | (-0.014000, -0.100885, 0.067399) |
| Global position (mm) | (-14.00, -100.88, 67.40) |
| Local transform (m) | (-0.014000, 0.014000, 0.014500) |
| Assembly context depth | 2 |
| transform2 (m) | (-0.014000, -0.100885, 0.067399) |
| **Physical** | |
| Mass | 0.000116 kg (0.116 g) |
| Volume | 1.476736e-08 m³ |
| Density | 7850.0 kg/m³ |
| Surface area | 6.798645e-05 m² |
| Body count | 1 |
| CoM (component-local, m) | (-0.000001, 0.001401, -0.000003) |
| CoM (global, m) | (-0.014001, -0.099484, 0.067396) |
| CoM (global, mm) | (-14.00, -99.48, 67.40) |
| **Inertia at origin (kg·m²)** | |
| Ixx, Iyy, Izz | 6.937235e-10, 8.731447e-11, 6.936831e-10 |
| Ixy, Ixz, Iyz | -1.930060e-14, 5.656132e-14, 3.539949e-14 |
| **Inertia at CoM (kg·m²)** | |
| Ixx, Iyy, Izz | 4.661804e-10, 8.731341e-11, 4.661409e-10 |
| Ixy, Ixz, Iyz | -1.180542e-13, 5.676973e-14, -4.448191e-13 |
| Bounding box (m) | 0.0035 × 0.0071 × 0.0035 |
| Bounding box (mm) | 3.50 × 7.10 × 3.50 |
| **Material & Appearance** | |
| Material | Steel |
| Appearance | Opaque_30_27_54 |
| Color (RGB 0-1) | (0.118, 0.106, 0.212) |
| Color (RGB 0-255) | (30, 27, 54) |

#### 🔧 COMPONENT: `PA2X6_2`

| Property | Value |
|---|---|
| Full path | `lidar_link:1+LD19_LiDAR:1+PA2X6_2:1` |
| Component name | PA2X6_2 |
| Depth | 2 |
| Path segments | lidar_link → LD19_LiDAR → PA2X6_2 |
| Parent path | `lidar_link:1+LD19_LiDAR:1` |
| **Transforms** | |
| Global position (m) | (0.014000, -0.128885, 0.067399) |
| Global position (mm) | (14.00, -128.88, 67.40) |
| Local transform (m) | (0.014000, -0.014000, 0.014500) |
| Assembly context depth | 2 |
| transform2 (m) | (0.014000, -0.128885, 0.067399) |
| **Physical** | |
| Mass | 0.000116 kg (0.116 g) |
| Volume | 1.476736e-08 m³ |
| Density | 7850.0 kg/m³ |
| Surface area | 6.798645e-05 m² |
| Body count | 1 |
| CoM (component-local, m) | (-0.000001, 0.001401, -0.000003) |
| CoM (global, m) | (0.013999, -0.127484, 0.067396) |
| CoM (global, mm) | (14.00, -127.48, 67.40) |
| **Inertia at origin (kg·m²)** | |
| Ixx, Iyy, Izz | 6.937235e-10, 8.731447e-11, 6.936831e-10 |
| Ixy, Ixz, Iyz | -1.930060e-14, 5.656132e-14, 3.539949e-14 |
| **Inertia at CoM (kg·m²)** | |
| Ixx, Iyy, Izz | 4.661804e-10, 8.731341e-11, 4.661409e-10 |
| Ixy, Ixz, Iyz | -1.180542e-13, 5.676973e-14, -4.448191e-13 |
| Bounding box (m) | 0.0035 × 0.0071 × 0.0035 |
| Bounding box (mm) | 3.50 × 7.10 × 3.50 |
| **Material & Appearance** | |
| Material | Steel |
| Appearance | Opaque_30_27_54 |
| Color (RGB 0-1) | (0.118, 0.106, 0.212) |
| Color (RGB 0-255) | (30, 27, 54) |

#### 🔧 COMPONENT: `PA2X6_3`

| Property | Value |
|---|---|
| Full path | `lidar_link:1+LD19_LiDAR:1+PA2X6_3:1` |
| Component name | PA2X6_3 |
| Depth | 2 |
| Path segments | lidar_link → LD19_LiDAR → PA2X6_3 |
| Parent path | `lidar_link:1+LD19_LiDAR:1` |
| **Transforms** | |
| Global position (m) | (0.014000, -0.100885, 0.072399) |
| Global position (mm) | (14.00, -100.88, 72.40) |
| Local transform (m) | (0.014000, 0.014000, 0.019500) |
| Assembly context depth | 2 |
| transform2 (m) | (0.014000, -0.100885, 0.072399) |
| **Physical** | |
| Mass | 0.000116 kg (0.116 g) |
| Volume | 1.476736e-08 m³ |
| Density | 7850.0 kg/m³ |
| Surface area | 6.798645e-05 m² |
| Body count | 1 |
| CoM (component-local, m) | (-0.000001, 0.001401, -0.000003) |
| CoM (global, m) | (0.013999, -0.099484, 0.072396) |
| CoM (global, mm) | (14.00, -99.48, 72.40) |
| **Inertia at origin (kg·m²)** | |
| Ixx, Iyy, Izz | 6.937235e-10, 8.731447e-11, 6.936831e-10 |
| Ixy, Ixz, Iyz | -1.930060e-14, 5.656132e-14, 3.539949e-14 |
| **Inertia at CoM (kg·m²)** | |
| Ixx, Iyy, Izz | 4.661804e-10, 8.731341e-11, 4.661409e-10 |
| Ixy, Ixz, Iyz | -1.180542e-13, 5.676973e-14, -4.448191e-13 |
| Bounding box (m) | 0.0035 × 0.0071 × 0.0035 |
| Bounding box (mm) | 3.50 × 7.10 × 3.50 |
| **Material & Appearance** | |
| Material | Steel |
| Appearance | Opaque_30_27_54 |
| Color (RGB 0-1) | (0.118, 0.106, 0.212) |
| Color (RGB 0-255) | (30, 27, 54) |

#### 🔧 COMPONENT: `PA2X6_4`

| Property | Value |
|---|---|
| Full path | `lidar_link:1+LD19_LiDAR:1+PA2X6_4:1` |
| Component name | PA2X6_4 |
| Depth | 2 |
| Path segments | lidar_link → LD19_LiDAR → PA2X6_4 |
| Parent path | `lidar_link:1+LD19_LiDAR:1` |
| **Transforms** | |
| Global position (m) | (-0.014000, -0.128885, 0.072399) |
| Global position (mm) | (-14.00, -128.88, 72.40) |
| Local transform (m) | (-0.014000, -0.014000, 0.019500) |
| Assembly context depth | 2 |
| transform2 (m) | (-0.014000, -0.128885, 0.072399) |
| **Physical** | |
| Mass | 0.000116 kg (0.116 g) |
| Volume | 1.476736e-08 m³ |
| Density | 7850.0 kg/m³ |
| Surface area | 6.798645e-05 m² |
| Body count | 1 |
| CoM (component-local, m) | (-0.000001, 0.001401, -0.000003) |
| CoM (global, m) | (-0.014001, -0.127484, 0.072396) |
| CoM (global, mm) | (-14.00, -127.48, 72.40) |
| **Inertia at origin (kg·m²)** | |
| Ixx, Iyy, Izz | 6.937235e-10, 8.731447e-11, 6.936831e-10 |
| Ixy, Ixz, Iyz | -1.930060e-14, 5.656132e-14, 3.539949e-14 |
| **Inertia at CoM (kg·m²)** | |
| Ixx, Iyy, Izz | 4.661804e-10, 8.731341e-11, 4.661409e-10 |
| Ixy, Ixz, Iyz | -1.180542e-13, 5.676973e-14, -4.448191e-13 |
| Bounding box (m) | 0.0035 × 0.0071 × 0.0035 |
| Bounding box (mm) | 3.50 × 7.10 × 3.50 |
| **Material & Appearance** | |
| Material | Steel |
| Appearance | Opaque_30_27_54 |
| Color (RGB 0-1) | (0.118, 0.106, 0.212) |
| Color (RGB 0-255) | (30, 27, 54) |

#### 🔧 COMPONENT: `Motor_Hub`

| Property | Value |
|---|---|
| Full path | `wheel_1_link:1+Wheel_Hub:2+Motor_Hub:1` |
| Component name | Motor_Hub |
| Depth | 2 |
| Path segments | wheel_1_link → Wheel_Hub → Motor_Hub |
| Parent path | `wheel_1_link:1+Wheel_Hub:2` |
| **Transforms** | |
| Global position (m) | (0.234076, -0.135144, -0.028962) |
| Global position (mm) | (234.08, -135.14, -28.96) |
| Local transform (m) | (0.000000, -0.000000, 0.000000) |
| Assembly context depth | 2 |
| transform2 (m) | (0.234076, -0.135144, -0.028962) |
| **Physical** | |
| Mass | 0.118971 kg (118.971 g) |
| Volume | 1.515551e-05 m³ |
| Density | 7850.0 kg/m³ |
| Surface area | 7.250133e-03 m² |
| Body count | 1 |
| CoM (component-local, m) | (0.000000, 0.000000, 0.003621) |
| CoM (global, m) | (0.234076, -0.135144, -0.025341) |
| CoM (global, mm) | (234.08, -135.14, -25.34) |
| **Inertia at origin (kg·m²)** | |
| Ixx, Iyy, Izz | 2.302890e-05, 2.302891e-05, 4.124951e-05 |
| Ixy, Ixz, Iyz | -1.227107e-19, -5.066935e-16, -1.394440e-21 |
| **Inertia at CoM (kg·m²)** | |
| Ixx, Iyy, Izz | 2.146927e-05, 2.146928e-05, 4.124951e-05 |
| Ixy, Ixz, Iyz | -1.227107e-19, 4.979097e-16, -1.394440e-21 |
| Bounding box (m) | 0.0576 × 0.0576 × 0.0110 |
| Bounding box (mm) | 57.60 × 57.60 × 11.00 |
| **Material & Appearance** | |
| Material | Steel |
| Appearance | ABS_White_1 |
| Color (RGB 0-1) | (0.075, 0.129, 0.502) |
| Color (RGB 0-255) | (19, 33, 128) |

#### 📦 SUBASSEMBLY: `OmniWheelwithHub`

| Property | Value |
|---|---|
| Full path | `wheel_1_link:1+Wheel_Hub:2+OmniWheelwithHub:1` |
| Component name | OmniWheelwithHub |
| Depth | 2 |
| Path segments | wheel_1_link → Wheel_Hub → OmniWheelwithHub |
| Parent path | `wheel_1_link:1+Wheel_Hub:2` |
| Child occurrences | 3 |
| **Transforms** | |
| Global position (m) | (0.200532, -0.107980, -0.019756) |
| Global position (mm) | (200.53, -107.98, -19.76) |
| Local transform (m) | (0.009206, -0.006753, -0.042631) |
| Assembly context depth | 2 |
| transform2 (m) | (0.200532, -0.107980, -0.019756) |

#### 🔧 COMPONENT: `Motor_Hub`

| Property | Value |
|---|---|
| Full path | `wheel_2_link:1+Wheel_Hub:3+Motor_Hub:1` |
| Component name | Motor_Hub |
| Depth | 2 |
| Path segments | wheel_2_link → Wheel_Hub → Motor_Hub |
| Parent path | `wheel_2_link:1+Wheel_Hub:3` |
| **Transforms** | |
| Global position (m) | (-0.000000, 0.270287, -0.028962) |
| Global position (mm) | (-0.00, 270.29, -28.96) |
| Local transform (m) | (0.000000, 0.000000, 0.000000) |
| Assembly context depth | 2 |
| transform2 (m) | (-0.000000, 0.270287, -0.028962) |
| **Physical** | |
| Mass | 0.118971 kg (118.971 g) |
| Volume | 1.515551e-05 m³ |
| Density | 7850.0 kg/m³ |
| Surface area | 7.250133e-03 m² |
| Body count | 1 |
| CoM (component-local, m) | (0.000000, 0.000000, 0.003621) |
| CoM (global, m) | (0.000000, 0.270287, -0.025341) |
| CoM (global, mm) | (0.00, 270.29, -25.34) |
| **Inertia at origin (kg·m²)** | |
| Ixx, Iyy, Izz | 2.302890e-05, 2.302891e-05, 4.124951e-05 |
| Ixy, Ixz, Iyz | -1.227107e-19, -5.066935e-16, -1.394440e-21 |
| **Inertia at CoM (kg·m²)** | |
| Ixx, Iyy, Izz | 2.146927e-05, 2.146928e-05, 4.124951e-05 |
| Ixy, Ixz, Iyz | -1.227107e-19, 4.979097e-16, -1.394440e-21 |
| Bounding box (m) | 0.0576 × 0.0576 × 0.0110 |
| Bounding box (mm) | 57.60 × 57.60 × 11.00 |
| **Material & Appearance** | |
| Material | Steel |
| Appearance | ABS_White_1 |
| Color (RGB 0-1) | (0.075, 0.129, 0.502) |
| Color (RGB 0-255) | (19, 33, 128) |

#### 📦 SUBASSEMBLY: `OmniWheelwithHub`

| Property | Value |
|---|---|
| Full path | `wheel_2_link:1+Wheel_Hub:3+OmniWheelwithHub:1` |
| Component name | OmniWheelwithHub |
| Depth | 2 |
| Path segments | wheel_2_link → Wheel_Hub → OmniWheelwithHub |
| Parent path | `wheel_2_link:1+Wheel_Hub:3` |
| Child occurrences | 3 |
| **Transforms** | |
| Global position (m) | (-0.006753, 0.227656, -0.019756) |
| Global position (mm) | (-6.75, 227.66, -19.76) |
| Local transform (m) | (0.009206, -0.006753, -0.042631) |
| Assembly context depth | 2 |
| transform2 (m) | (-0.006753, 0.227656, -0.019756) |

#### 🔧 COMPONENT: `Motor_Hub`

| Property | Value |
|---|---|
| Full path | `wheel_3_link:1+Wheel_Hub:1+Motor_Hub:1` |
| Component name | Motor_Hub |
| Depth | 2 |
| Path segments | wheel_3_link → Wheel_Hub → Motor_Hub |
| Parent path | `wheel_3_link:1+Wheel_Hub:1` |
| **Transforms** | |
| Global position (m) | (-0.234076, -0.135144, -0.028962) |
| Global position (mm) | (-234.08, -135.14, -28.96) |
| Local transform (m) | (0.000000, -0.000000, 0.000000) |
| Assembly context depth | 2 |
| transform2 (m) | (-0.234076, -0.135144, -0.028962) |
| **Physical** | |
| Mass | 0.118971 kg (118.971 g) |
| Volume | 1.515551e-05 m³ |
| Density | 7850.0 kg/m³ |
| Surface area | 7.250133e-03 m² |
| Body count | 1 |
| CoM (component-local, m) | (0.000000, 0.000000, 0.003621) |
| CoM (global, m) | (-0.234076, -0.135144, -0.025341) |
| CoM (global, mm) | (-234.08, -135.14, -25.34) |
| **Inertia at origin (kg·m²)** | |
| Ixx, Iyy, Izz | 2.302890e-05, 2.302891e-05, 4.124951e-05 |
| Ixy, Ixz, Iyz | -1.227107e-19, -5.066935e-16, -1.394440e-21 |
| **Inertia at CoM (kg·m²)** | |
| Ixx, Iyy, Izz | 2.146927e-05, 2.146928e-05, 4.124951e-05 |
| Ixy, Ixz, Iyz | -1.227107e-19, 4.979097e-16, -1.394440e-21 |
| Bounding box (m) | 0.0576 × 0.0576 × 0.0110 |
| Bounding box (mm) | 57.60 × 57.60 × 11.00 |
| **Material & Appearance** | |
| Material | Steel |
| Appearance | ABS_White_1 |
| Color (RGB 0-1) | (0.075, 0.129, 0.502) |
| Color (RGB 0-255) | (19, 33, 128) |

#### 📦 SUBASSEMBLY: `OmniWheelwithHub`

| Property | Value |
|---|---|
| Full path | `wheel_3_link:1+Wheel_Hub:1+OmniWheelwithHub:1` |
| Component name | OmniWheelwithHub |
| Depth | 2 |
| Path segments | wheel_3_link → Wheel_Hub → OmniWheelwithHub |
| Parent path | `wheel_3_link:1+Wheel_Hub:1` |
| Child occurrences | 3 |
| **Transforms** | |
| Global position (m) | (-0.193780, -0.119676, -0.019756) |
| Global position (mm) | (-193.78, -119.68, -19.76) |
| Local transform (m) | (0.009206, -0.006753, -0.042631) |
| Assembly context depth | 2 |
| transform2 (m) | (-0.193780, -0.119676, -0.019756) |

### Depth 3

#### 📦 SUBASSEMBLY: `Converter_DCDC_RECOM_R_78E_0_5_THT`

| Property | Value |
|---|---|
| Full path | `base_link:1+PCB Housing:1+Main_PCB:1+Converter_DCDC_RECOM_R-78E-0.5_THT:1` |
| Component name | Converter_DCDC_RECOM_R-78E-0.5_THT |
| Depth | 3 |
| Path segments | base_link → PCB_Housing → Main_PCB → Converter_DCDC_RECOM_R_78E_0_5_THT |
| Parent path | `base_link:1+PCB Housing:1+Main_PCB:1` |
| Child occurrences | 1 |
| **Transforms** | |
| Global position (m) | (-0.027107, 0.004990, -0.004665) |
| Global position (mm) | (-27.11, 4.99, -4.67) |
| Local transform (m) | (0.168408, -0.066408, 0.001595) |
| Assembly context depth | 3 |
| transform2 (m) | (-0.027107, 0.004990, -0.004665) |

#### 🔧 COMPONENT: `KiwiDrive_PCB`

| Property | Value |
|---|---|
| Full path | `base_link:1+PCB Housing:1+Main_PCB:1+KiwiDrive_PCB:1` |
| Component name | KiwiDrive_PCB |
| Depth | 3 |
| Path segments | base_link → PCB_Housing → Main_PCB → KiwiDrive_PCB |
| Parent path | `base_link:1+PCB Housing:1+Main_PCB:1` |
| **Transforms** | |
| Global position (m) | (-0.000414, -0.174060, -0.006260) |
| Global position (mm) | (-0.41, -174.06, -6.26) |
| Local transform (m) | (0.000000, 0.000000, 0.000000) |
| Assembly context depth | 3 |
| transform2 (m) | (-0.000414, -0.174060, -0.006260) |
| **Physical** | |
| Mass | 0.094609 kg (94.609 g) |
| Volume | 1.205206e-05 m³ |
| Density | 7850.0 kg/m³ |
| Surface area | 1.748627e-02 m² |
| Body count | 1 |
| CoM (component-local, m) | (0.150552, -0.096414, 0.000755) |
| CoM (global, m) | (0.150138, -0.270474, -0.005505) |
| CoM (global, mm) | (150.14, -270.47, -5.51) |
| **Inertia at origin (kg·m²)** | |
| Ixx, Iyy, Izz | 9.747146e-04, 2.230191e-03, 3.204762e-03 |
| Ixy, Ixz, Iyz | 1.373339e-03, -1.075388e-05, 6.886816e-06 |
| **Inertia at CoM (kg·m²)** | |
| Ixx, Iyy, Izz | 9.520841e-05, 8.573879e-05, 1.809112e-04 |
| Ixy, Ixz, Iyz | 5.999534e-08, 3.388132e-21, -1.694066e-21 |
| Bounding box (m) | 0.1433 × 0.1256 × 0.0015 |
| Bounding box (mm) | 143.33 × 125.65 × 1.51 |
| **Material & Appearance** | |
| Material | Steel |
| Appearance | Paint_Enamel_Glossy_White |
| Color (RGB 0-1) | (0.965, 0.965, 0.953) |
| Color (RGB 0-255) | (246, 246, 243) |

#### 📦 SUBASSEMBLY: `PinHeader_1x02_P2_54mm_Vertical`

| Property | Value |
|---|---|
| Full path | `base_link:1+PCB Housing:1+Main_PCB:1+PinHeader_1x02_P2.54mm_Vertical:1` |
| Component name | PinHeader_1x02_P2.54mm_Vertical |
| Depth | 3 |
| Path segments | base_link → PCB_Housing → Main_PCB → PinHeader_1x02_P2_54mm_Vertical |
| Parent path | `base_link:1+PCB Housing:1+Main_PCB:1` |
| Child occurrences | 1 |
| **Transforms** | |
| Global position (m) | (0.039357, 0.003055, -0.004665) |
| Global position (mm) | (39.36, 3.05, -4.67) |
| Local transform (m) | (0.133500, -0.123000, 0.001595) |
| Assembly context depth | 3 |
| transform2 (m) | (0.039357, 0.003055, -0.004665) |

#### 📦 SUBASSEMBLY: `PinHeader_1x04_P2_54mm_Vertical`

| Property | Value |
|---|---|
| Full path | `base_link:1+PCB Housing:1+Main_PCB:1+PinHeader_1x04_P2.54mm_Vertical:1` |
| Component name | PinHeader_1x04_P2.54mm_Vertical |
| Depth | 3 |
| Path segments | base_link → PCB_Housing → Main_PCB → PinHeader_1x04_P2_54mm_Vertical |
| Parent path | `base_link:1+PCB Housing:1+Main_PCB:1` |
| Child occurrences | 1 |
| **Transforms** | |
| Global position (m) | (-0.010674, 0.022090, -0.004665) |
| Global position (mm) | (-10.67, 22.09, -4.67) |
| Local transform (m) | (0.175000, -0.089190, 0.001595) |
| Assembly context depth | 3 |
| transform2 (m) | (-0.010674, 0.022090, -0.004665) |

#### 📦 SUBASSEMBLY: `PinHeader_1x10_P2_54mm_Vertical`

| Property | Value |
|---|---|
| Full path | `base_link:1+PCB Housing:1+Main_PCB:1+PinHeader_1x10_P2.54mm_Vertical:1` |
| Component name | PinHeader_1x10_P2.54mm_Vertical |
| Depth | 3 |
| Path segments | base_link → PCB_Housing → Main_PCB → PinHeader_1x10_P2_54mm_Vertical |
| Parent path | `base_link:1+PCB Housing:1+Main_PCB:1` |
| Child occurrences | 1 |
| **Transforms** | |
| Global position (m) | (-0.015578, 0.013485, -0.004665) |
| Global position (mm) | (-15.58, 13.48, -4.67) |
| Local transform (m) | (0.170000, -0.080640, 0.001595) |
| Assembly context depth | 3 |
| transform2 (m) | (-0.015578, 0.013485, -0.004665) |

#### 🔧 COMPONENT: `6mm_Mount`

| Property | Value |
|---|---|
| Full path | `wheel_1_link:1+Wheel_Hub:2+OmniWheelwithHub:1+6mm_Mount:1` |
| Component name | 6mm_Mount |
| Depth | 3 |
| Path segments | wheel_1_link → Wheel_Hub → OmniWheelwithHub → 6mm_Mount |
| Parent path | `wheel_1_link:1+Wheel_Hub:2+OmniWheelwithHub:1` |
| **Transforms** | |
| Global position (m) | (0.246981, -0.142594, -0.028962) |
| Global position (mm) | (246.98, -142.59, -28.96) |
| Local transform (m) | (-0.009206, 0.006753, 0.057533) |
| Assembly context depth | 3 |
| transform2 (m) | (0.246981, -0.142594, -0.028962) |
| **Physical** | |
| Mass | 0.006982 kg (6.982 g) |
| Volume | 6.982289e-06 m³ |
| Density | 1000.0 kg/m³ |
| Surface area | 2.945813e-03 m² |
| Body count | 1 |
| CoM (component-local, m) | (0.000046, 0.013287, -0.000046) |
| CoM (global, m) | (0.247027, -0.129307, -0.029008) |
| CoM (global, mm) | (247.03, -129.31, -29.01) |
| **Inertia at origin (kg·m²)** | |
| Ixx, Iyy, Izz | 1.824828e-06, 3.446660e-07, 1.824829e-06 |
| Ixy, Ixz, Iyz | -6.243941e-09, 9.699569e-14, 6.254708e-09 |
| **Inertia at CoM (kg·m²)** | |
| Ixx, Iyy, Izz | 5.920723e-07, 3.446366e-07, 5.920737e-07 |
| Ixy, Ixz, Iyz | -1.989224e-09, -1.461245e-11, 1.992865e-09 |
| Bounding box (m) | 0.0218 × 0.0295 × 0.0218 |
| Bounding box (mm) | 21.80 × 29.50 × 21.80 |
| **Material & Appearance** | |
| Material | Generic |
| Appearance | Opaque_191_191_191 |
| Color (RGB 0-1) | (0.749, 0.749, 0.749) |
| Color (RGB 0-255) | (191, 191, 191) |

#### 🔧 COMPONENT: `Back_Spacer`

| Property | Value |
|---|---|
| Full path | `wheel_1_link:1+Wheel_Hub:2+OmniWheelwithHub:1+Back Spacer:1` |
| Component name | Back Spacer |
| Depth | 3 |
| Path segments | wheel_1_link → Wheel_Hub → OmniWheelwithHub → Back_Spacer |
| Parent path | `wheel_1_link:1+Wheel_Hub:2+OmniWheelwithHub:1` |
| **Transforms** | |
| Global position (m) | (0.246201, -0.142144, -0.028962) |
| Global position (mm) | (246.20, -142.14, -28.96) |
| Local transform (m) | (-0.009206, 0.006753, 0.056632) |
| Assembly context depth | 3 |
| transform2 (m) | (0.246201, -0.142144, -0.028962) |
| **Physical** | |
| Mass | 0.002393 kg (2.393 g) |
| Volume | 2.393014e-06 m³ |
| Density | 1000.0 kg/m³ |
| Surface area | 1.250150e-03 m² |
| Body count | 1 |
| CoM (component-local, m) | (-0.000000, 0.003500, 0.000000) |
| CoM (global, m) | (0.246201, -0.138644, -0.028962) |
| CoM (global, mm) | (246.20, -138.64, -28.96) |
| **Inertia at origin (kg·m²)** | |
| Ixx, Iyy, Izz | 1.150960e-07, 1.523277e-07, 1.150960e-07 |
| Ixy, Ixz, Iyz | 1.879708e-17, -8.881784e-23, 1.110223e-23 |
| **Inertia at CoM (kg·m²)** | |
| Ixx, Iyy, Izz | 8.578160e-08, 1.523277e-07, 8.578158e-08 |
| Ixy, Ixz, Iyz | 1.554312e-23, -8.881784e-23, 2.664535e-23 |
| Bounding box (m) | 0.0218 × 0.0070 × 0.0218 |
| Bounding box (mm) | 21.80 × 7.00 × 21.80 |
| **Material & Appearance** | |
| Material | Generic |
| Appearance | Opaque_191_191_191 |
| Color (RGB 0-1) | (0.749, 0.749, 0.749) |
| Color (RGB 0-255) | (191, 191, 191) |

#### 📦 SUBASSEMBLY: `Omni_Wheel`

| Property | Value |
|---|---|
| Full path | `wheel_1_link:1+Wheel_Hub:2+OmniWheelwithHub:1+Omni Wheel:1` |
| Component name | Omni Wheel |
| Depth | 3 |
| Path segments | wheel_1_link → Wheel_Hub → OmniWheelwithHub → Omni_Wheel |
| Parent path | `wheel_1_link:1+Wheel_Hub:2+OmniWheelwithHub:1` |
| Child occurrences | 3 |
| **Transforms** | |
| Global position (m) | (0.264734, -0.152844, -0.028962) |
| Global position (mm) | (264.73, -152.84, -28.96) |
| Local transform (m) | (-0.009206, 0.006753, 0.078033) |
| Assembly context depth | 3 |
| transform2 (m) | (0.264734, -0.152844, -0.028962) |

#### 🔧 COMPONENT: `6mm_Mount`

| Property | Value |
|---|---|
| Full path | `wheel_2_link:1+Wheel_Hub:3+OmniWheelwithHub:1+6mm_Mount:1` |
| Component name | 6mm_Mount |
| Depth | 3 |
| Path segments | wheel_2_link → Wheel_Hub → OmniWheelwithHub → 6mm_Mount |
| Parent path | `wheel_2_link:1+Wheel_Hub:3+OmniWheelwithHub:1` |
| **Transforms** | |
| Global position (m) | (-0.000000, 0.285189, -0.028962) |
| Global position (mm) | (-0.00, 285.19, -28.96) |
| Local transform (m) | (-0.009206, 0.006753, 0.057533) |
| Assembly context depth | 3 |
| transform2 (m) | (-0.000000, 0.285189, -0.028962) |
| **Physical** | |
| Mass | 0.006982 kg (6.982 g) |
| Volume | 6.982289e-06 m³ |
| Density | 1000.0 kg/m³ |
| Surface area | 2.945813e-03 m² |
| Body count | 1 |
| CoM (component-local, m) | (0.000046, 0.013287, -0.000046) |
| CoM (global, m) | (0.000046, 0.298476, -0.029008) |
| CoM (global, mm) | (0.05, 298.48, -29.01) |
| **Inertia at origin (kg·m²)** | |
| Ixx, Iyy, Izz | 1.824828e-06, 3.446660e-07, 1.824829e-06 |
| Ixy, Ixz, Iyz | -6.243941e-09, 9.699569e-14, 6.254708e-09 |
| **Inertia at CoM (kg·m²)** | |
| Ixx, Iyy, Izz | 5.920723e-07, 3.446366e-07, 5.920737e-07 |
| Ixy, Ixz, Iyz | -1.989224e-09, -1.461245e-11, 1.992865e-09 |
| Bounding box (m) | 0.0218 × 0.0295 × 0.0218 |
| Bounding box (mm) | 21.80 × 29.50 × 21.80 |
| **Material & Appearance** | |
| Material | Generic |
| Appearance | Opaque_191_191_191 |
| Color (RGB 0-1) | (0.749, 0.749, 0.749) |
| Color (RGB 0-255) | (191, 191, 191) |
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

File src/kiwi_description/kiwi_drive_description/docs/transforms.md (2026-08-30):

# Transformation Matrices - Kiwi_Drive_Full_Assembly_Copy_Copy

Homogeneous transformation matrices between consecutive frames.
Convention: URDF RPY (XYZ extrinsic / ZYX intrinsic).

## Notation

### Frames

| Index | Link |
|---|---|
| $L_{0}$ | base_link |
| $L_{1}$ | wheel_1_link_Omni_Wheel |
| $L_{2}$ | wheel_2_link_Omni_Wheel |
| $L_{3}$ | wheel_3_link_Omni_Wheel |
| $L_{4}$ | Lidar_Mounting_Plate |
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

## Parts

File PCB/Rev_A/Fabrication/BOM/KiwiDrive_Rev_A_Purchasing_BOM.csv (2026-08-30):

Reference | Qty | Value | DNP | Exclude from BOM | Exclude from Board | Footprint | Datasheet
DCmotorWithEncoder1,DCmotorWithEncoder2,DCmotorWithEncoder3 | 3 |  |  |  |  | 25GA_Motor_Encoder:25GA_Motor_Encoder_6Pin
J1 | 1 | Screw_Terminal_01x02 |  |  |  | Connector_AMASS:AMASS_XT30PW-F_1x02_P2.50mm_Horizontal
J2 | 1 | Conn_01x10 |  |  |  | Connector_PinHeader_2.54mm:PinHeader_1x10_P2.54mm_Vertical
J3 | 1 | Conn_01x04 |  |  |  | Connector_PinHeader_2.54mm:PinHeader_1x04_P2.54mm_Vertical
J4 | 1 | Conn_01x02 |  |  |  | Connector_PinHeader_2.54mm:PinHeader_1x02_P2.54mm_Vertical
TP1,TP2,TP3,TP4,TP5,TP6,TP7,TP8,TP9,TP10,TP11,TP12,TP13,TP14,TP15,TP16,TP17,TP18,TP19,TP20,TP21,TP22,TP23,TP24,TP25,TP26,TP27,TP28,TP29 | 29 | TestPoint |  |  |  | TestPoint:TestPoint_Pad_1.0x1.0mm
U1,U2,U3 | 3 | TB6612FNG |  |  |  | TB6612FNG:TB6612FNG
U4 | 1 | R-78E5.0-1.0 |  |  |  | Converter_DCDC:Converter_DCDC_RECOM_R-78E-0.5_THT | https://www.recom-power.com/pdf/Innoline/R-78Exx-1.0.pdf
U5 | 1 | ESP32-DEVKIT-V1 |  |  |  | ESP32:MODULE_ESP32_DEVKIT_V1

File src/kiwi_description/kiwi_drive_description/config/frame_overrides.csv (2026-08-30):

link | parent_joint | joint_type | rule | original_roll_deg | original_pitch_deg | original_yaw_deg | post_roll_deg | post_pitch_deg | post_yaw_deg | role
Lidar_Mounting_Plate | base_link_to_lidar_link | fixed | keep | 0.000000 | 0.000000 | 0.000000 | 0.000000 | 0.000000 | 0.000000 | unchanged
base_link |  | root | auto | 0.000000 | 0.000000 | -120.000000 | 0.000000 | 0.000000 | 0.000000 | root_x_forward_z_up
wheel_1_link_Omni_Wheel | wheel_1_to_base_link | continuous | auto | -0.555057 | -27.752017 | 150.256082 | -91.004932 | 1.782209 | 60.576236 | revolute_axis_z
wheel_2_link_Omni_Wheel | wheel_2_to_base_link | continuous | auto | 1.839926 | -28.514831 | -90.886073 | 90.207588 | -0.002236 | 0.616989 | revolute_axis_z
wheel_3_link_Omni_Wheel | wheel_3_to_base_link | continuous | auto | -0.124384 | -29.965614 | 30.060881 | -88.787154 | 2.046426 | -59.337138 | revolute_axis_z

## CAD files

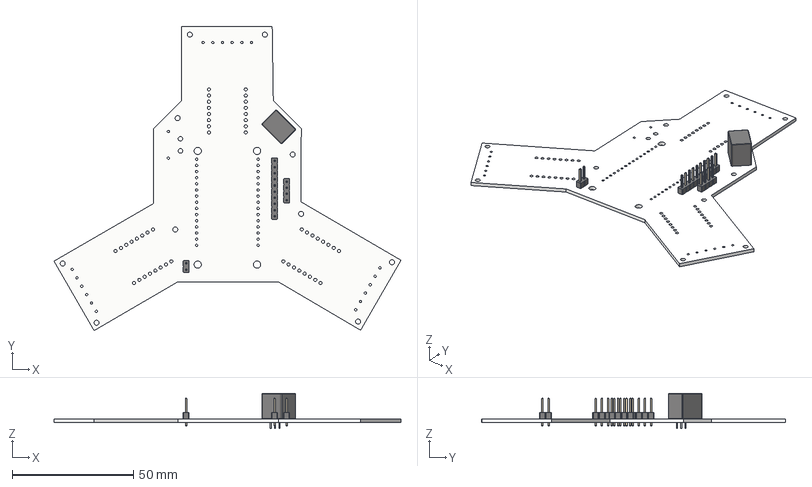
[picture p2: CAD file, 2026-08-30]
CAD/Reference_Models/Electronics/Main_PCB.step
143.3 x 125.6 x 14.5 mm

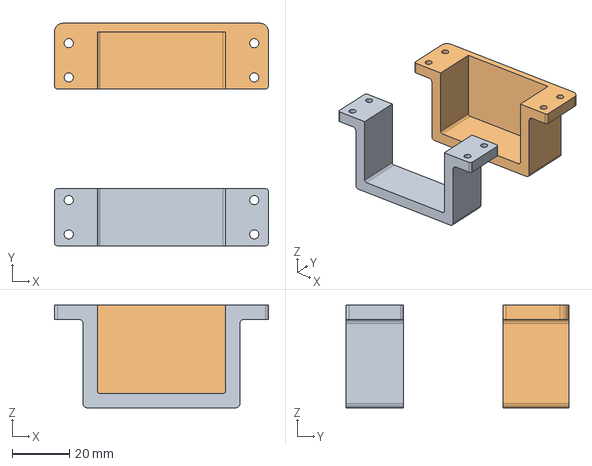
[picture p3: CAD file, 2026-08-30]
CAD/Printed_Parts/STEP/Battery_Mount_Assembly.step
75.0 x 78.0 x 36.0 mm

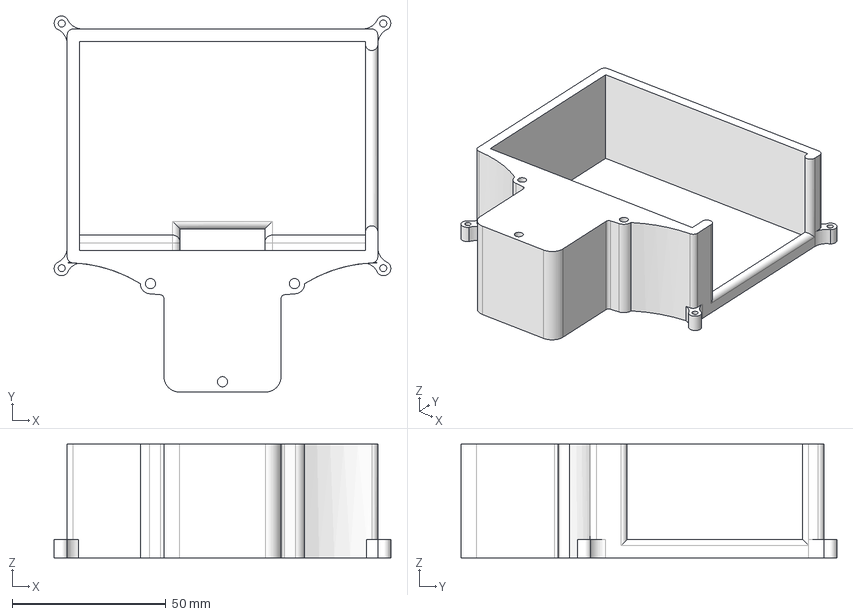
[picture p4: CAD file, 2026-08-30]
CAD/Printed_Parts/STEP/Lidar_Mounting_Plate.step
109.4 x 122.2 x 37.0 mm

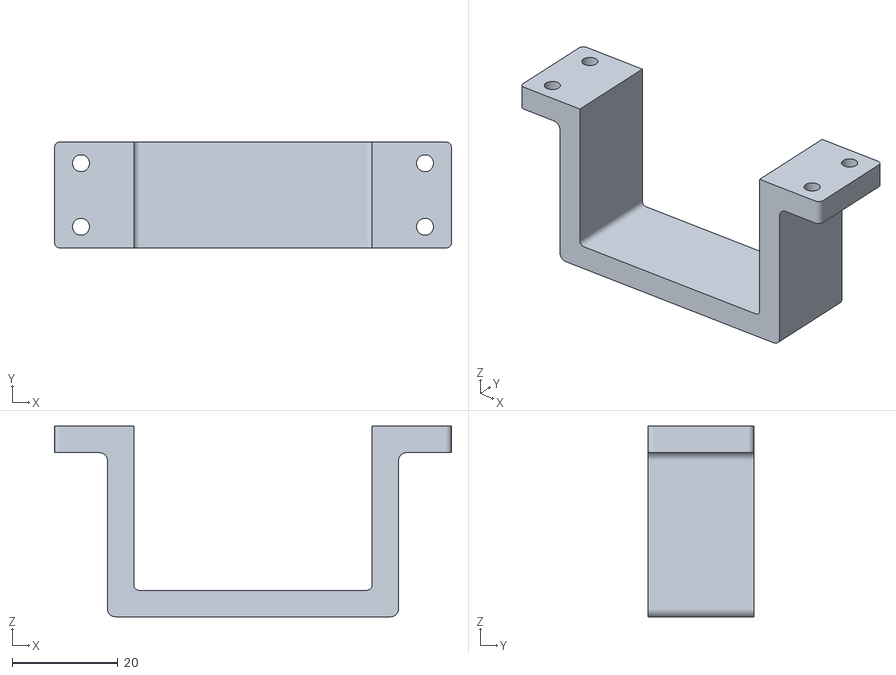
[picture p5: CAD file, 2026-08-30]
CAD/Printed_Parts/STL/Battery_Mount_Front.stl
75.0 x 20.0 x 36.0

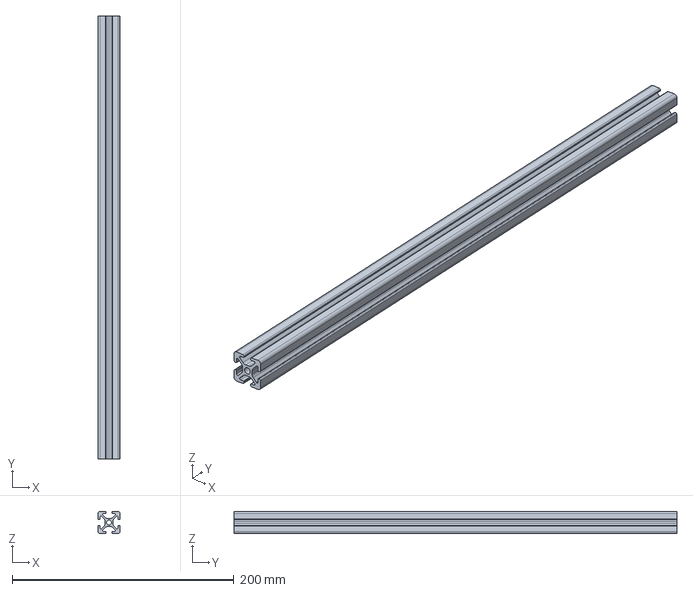
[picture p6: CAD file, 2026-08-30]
CAD/Reference_Models/Aluminum_Extrusion/2020_400mm_Aluminum_Extrusion.step
20.0 x 400.0 x 20.0 mm

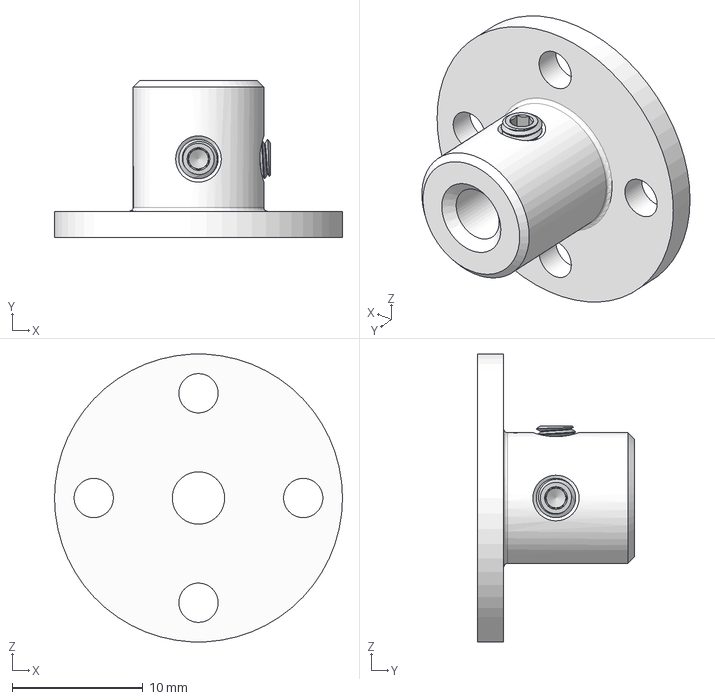
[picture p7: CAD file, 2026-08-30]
CAD/Reference_Models/Couplings/4mm_Rigid_Flange_Coupling.step
22.0 x 12.0 x 22.0 mm

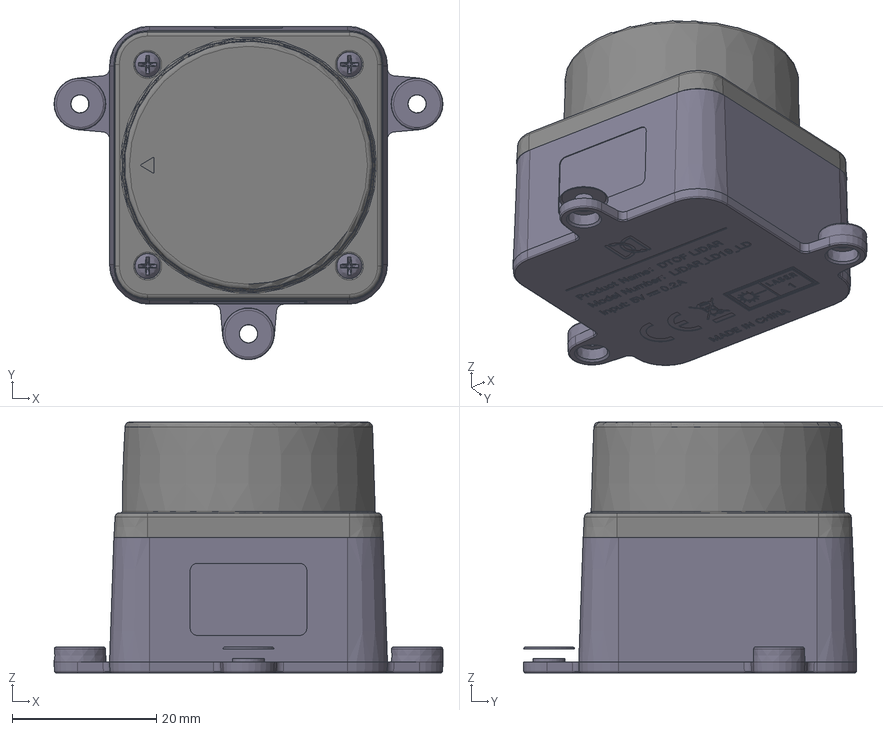
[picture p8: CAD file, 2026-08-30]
CAD/Reference_Models/Lidar/LD19_LiDAR.step
54.0 x 46.3 x 34.8 mm

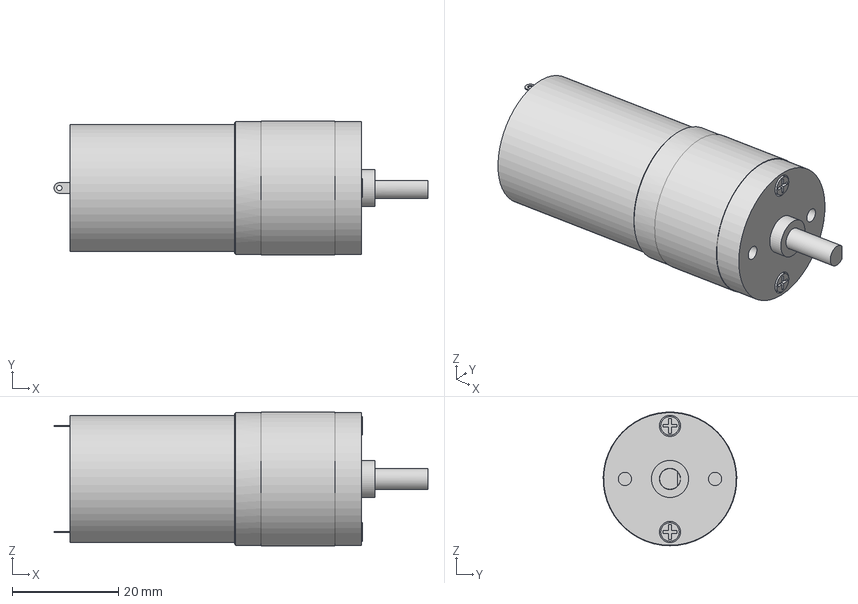
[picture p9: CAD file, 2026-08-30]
CAD/Reference_Models/Motor/JGA25-370DC_Motor.step
70.5 x 25.2 x 25.2 mm

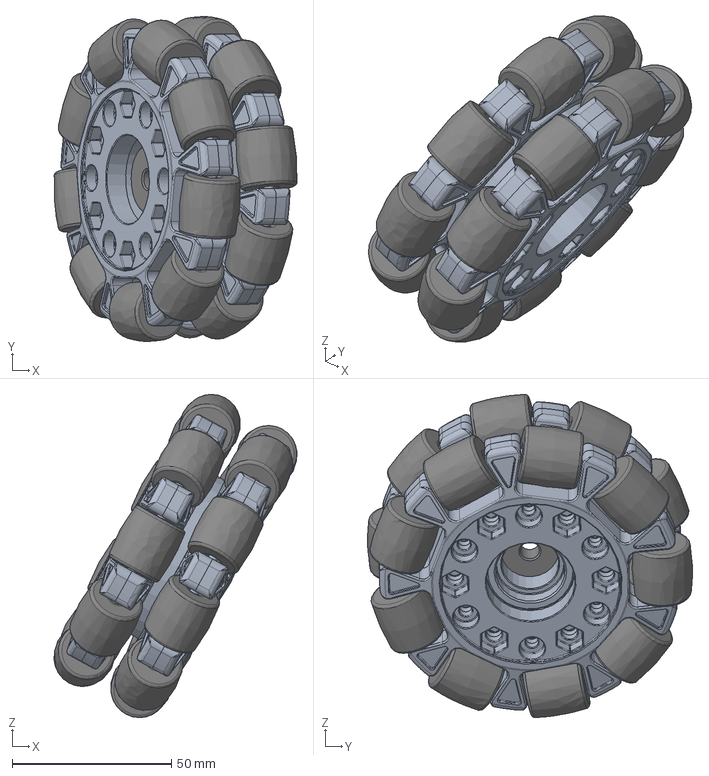
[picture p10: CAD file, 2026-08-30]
CAD/Reference_Models/Omni_Wheel/Omni_Wheel.step
76.4 x 102.2 x 101.7 mm

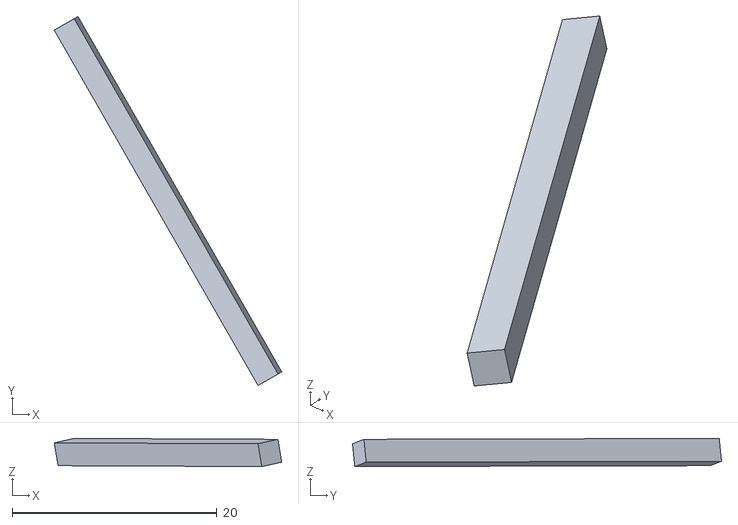
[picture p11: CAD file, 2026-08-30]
src/kiwi_description/kiwi_drive_description/meshes/base_link/base_link_collision.stl
22.2 x 36.0 x 2.75

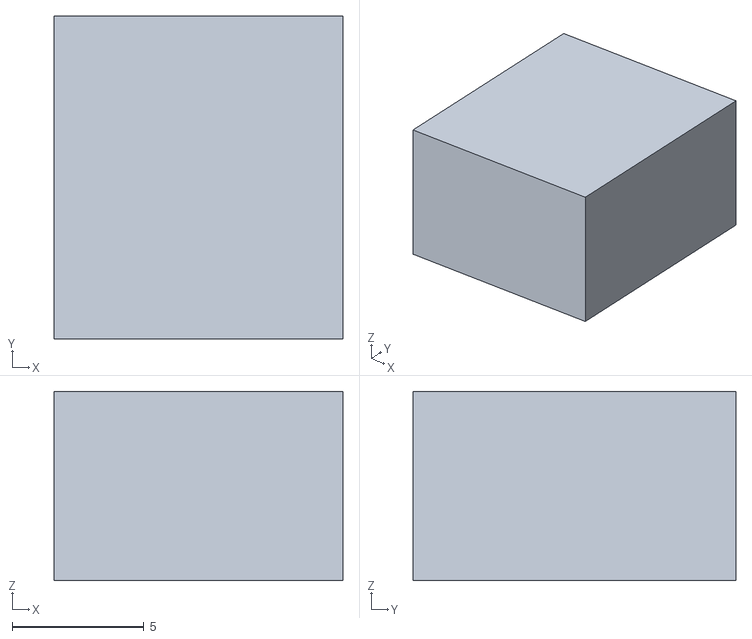
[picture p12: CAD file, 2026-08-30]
src/kiwi_description/kiwi_drive_description/meshes/lidar_link/Lidar_Mounting_Plate_collision.stl
10.9 x 12.3 x 7.18

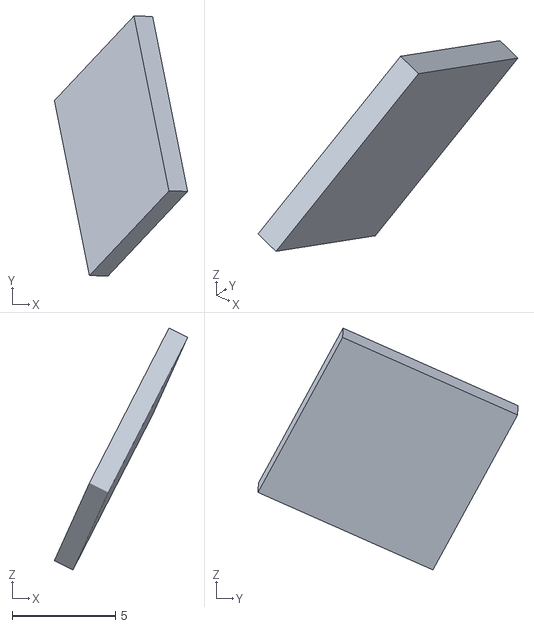
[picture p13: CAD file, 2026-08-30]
src/kiwi_description/kiwi_drive_description/meshes/wheel_1_link/wheel_1_link_Omni_Wheel_collision.stl
6.47 x 12.6 x 11.7

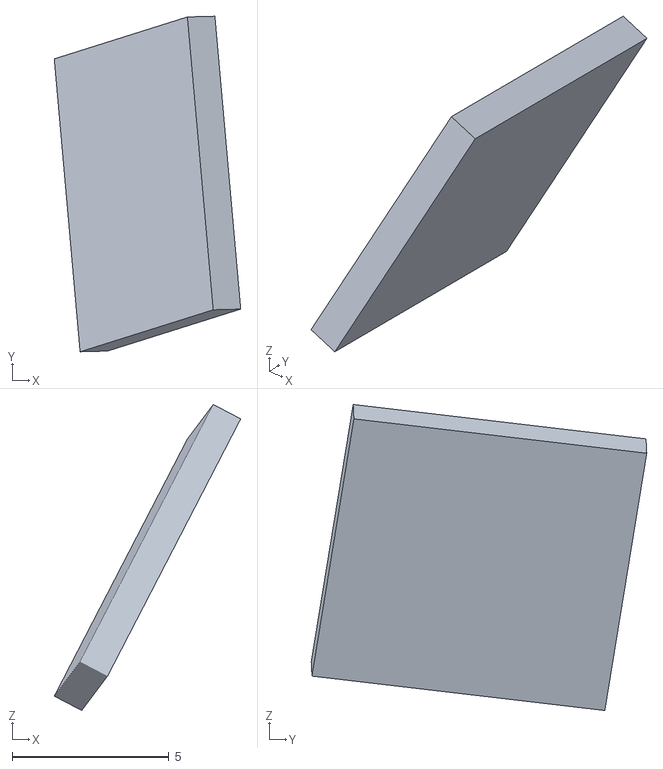
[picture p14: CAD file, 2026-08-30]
src/kiwi_description/kiwi_drive_description/meshes/wheel_2_link/wheel_2_link_Omni_Wheel_collision.stl
5.95 x 10.7 x 9.77

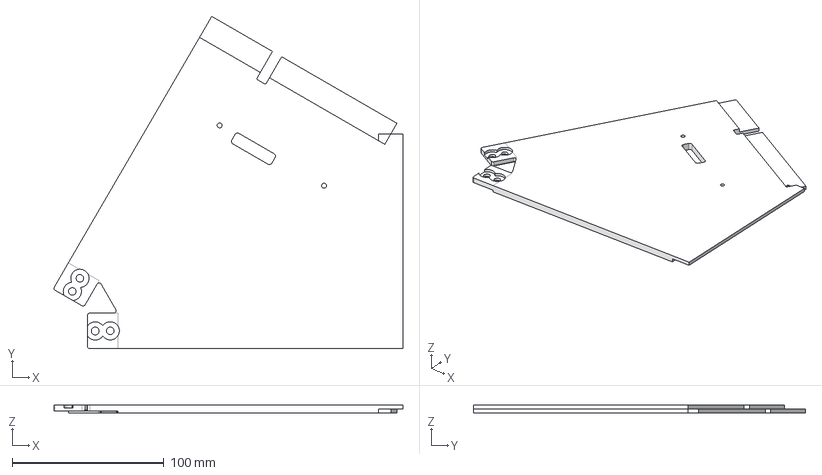
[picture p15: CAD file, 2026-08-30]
CAD/Printed_Parts/STEP/Front_Left_Base_Plate.step
230.1 x 219.0 x 5.43 mm

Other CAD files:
CAD/Printed_Parts/STL/Battery_Mount_Back.stl
CAD/Printed_Parts/STEP/2020_Aluminum_Extrusion_Mounting_Spacer.step
CAD/Printed_Parts/STEP/Motor_Mount.step
CAD/Printed_Parts/Fusion_360/2020_Aluminum_Extrusion_Mounting_Spacer.f3d
CAD/Printed_Parts/Fusion_360/Battery_Mount_Assembly.f3d
CAD/Printed_Parts/Fusion_360/Front_Left_Base_Plate.f3d
CAD/Printed_Parts/Fusion_360/Front_Right_Base_Plate.f3d
CAD/Printed_Parts/Fusion_360/Lidar_Mounting_Plate.f3d
CAD/Printed_Parts/Fusion_360/Motor_Hub.f3d
CAD/Printed_Parts/Fusion_360/Motor_Mount.f3d
CAD/Printed_Parts/Fusion_360/PCB_Mounting_Enclosure.f3d
CAD/Printed_Parts/Fusion_360/Rear_Base_Plate.f3d
CAD/Printed_Parts/Fusion_360/Top_Plate.f3d
CAD/Printed_Parts/STEP/Front_Right_Base_Plate.step
CAD/Printed_Parts/STEP/Motor_Hub.step
CAD/Printed_Parts/STEP/PCB_Mounting_Enclosure.step
CAD/Printed_Parts/STEP/Rear_Base_Plate.step
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

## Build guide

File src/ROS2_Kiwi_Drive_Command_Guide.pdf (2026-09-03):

3-Axis Holonomic Drive - ROS 2 Command Guide | Page 1

# ROS 2 Quick Command Guide

## Kiwi Drive Robot - Raspberry Pi / ESP32 Integration

### Important: Run these commands in every new terminal before using the workspace:

### Source ROS 2 + Workspace

source /opt/ros/lyrical/setup.bash cd ~/robot_ws
source install/setup.bash

# 1. Build the ROS 2 Workspace

COMMAND | Build the complete ROS 2 workspace.
PURPOSE | Use this after changing ROS 2 packages, Python nodes, launch files, URDF files, configuration files, or package dependencies.
TERMINALS NEEDED | 1 Terminal

### Terminal 1

cd ~/robot_ws
colcon build --symlink-install source install/setup.bash

# Build only one package:

colcon build --symlink-install --packages-select PACKAGE_NAME

# Example:

colcon build --symlink-install --packages-select kiwi_drive_description

# 2. View the Robot Model in RViz

COMMAND | Launch the Kiwi Drive robot model in RViz.
PURPOSE | Displays the robot URDF and TF frames so the robot model, joints, links, and coordinate frames can be inspected.
TERMINALS NEEDED | 1 Terminal

### Terminal 1

source /opt/ros/lyrical/setup.bash cd ~/robot_ws
source install/setup.bash

ros2 launch kiwi_drive_description display.launch.py

# 3. Start the LD19 LiDAR

COMMAND | Start the LD19 LiDAR ROS 2 driver.
PURPOSE | Starts the LiDAR and begins publishing laser scan data to the /scan topic.
TERMINALS NEEDED | 1 Terminal

### Terminal 1

source /opt/ros/lyrical/setup.bash cd ~/robot_ws
source install/setup.bash

ros2 launch ldlidar_ros2 ld19.launch.py

# 4. Start the LiDAR and View Live Scan Data

COMMAND | Run the LD19 LiDAR and view the raw /scan messages.
PURPOSE | Confirms that the LiDAR driver is running and that actual laser-distance measurements are being published.
TERMINALS NEEDED | 2 Terminals

### Terminal 1 - Start LiDAR

source /opt/ros/lyrical/setup.bash cd ~/robot_ws
source install/setup.bash

ros2 launch ldlidar_ros2 ld19.launch.py

### Terminal 2 - View Scan Data

source /opt/ros/lyrical/setup.bash cd ~/robot_ws
source install/setup.bash

ros2 topic echo /scan

# 5. Check the LiDAR Publishing Rate

COMMAND | Measure how frequently the LiDAR publishes /scan messages.
PURPOSE | Useful for checking whether the LiDAR is publishing at the expected rate and for diagnosing performance problems.
TERMINALS NEEDED | 2 Terminals

### Terminal 1 - Start LiDAR

source /opt/ros/lyrical/setup.bash cd ~/robot_ws
source install/setup.bash

ros2 launch ldlidar_ros2 ld19.launch.py

### Terminal 2 - Check /scan Rate

source /opt/ros/lyrical/setup.bash cd ~/robot_ws
source install/setup.bash

ros2 topic hz /scan

# 6. List Available ROS 2 Topics

COMMAND | List all currently available ROS 2 topics.
PURPOSE | Use this to see what information is currently being published or subscribed to in the ROS 2 system.
TERMINALS NEEDED | 1 Terminal

### Terminal 1

ros2 topic list

Common topics:
/cmd_vel
/scan
/odom
/tf
/tf_static

# 7. List Running ROS 2 Nodes

COMMAND | List all currently running ROS 2 nodes.
PURPOSE | Useful for checking whether expected nodes such as the serial bridge, LiDAR driver, robot_state_publisher, or odometry nodes are actually running.
TERMINALS NEEDED | 1 Terminal

### Terminal 1

ros2 node list

# 8. Check Information About a ROS 2 Topic

COMMAND | Display information about a ROS 2 topic.
PURPOSE | Shows the topic message type and the number of publishers and subscribers.
TERMINALS NEEDED | 1 Terminal

### Terminal 1

ros2 topic info /cmd_vel
ros2 topic info /scan
ros2 topic info /odom

# 9. Move the Robot Forward

COMMAND | Continuously publish a forward velocity command to /cmd_vel.
PURPOSE | Moves the robot forward using ROS 2 autonomous control. The ESP32 must be in AUTO mode and the serial bridge must already be running.
TERMINALS NEEDED | 2 Terminals

### Terminal 1 - Serial Bridge

source /opt/ros/lyrical/setup.bash cd ~/robot_ws
source install/setup.bash

# Start the Kiwi serial bridge here.

### Terminal 2 - Forward Command

source /opt/ros/lyrical/setup.bash cd ~/robot_ws
source install/setup.bash

ros2 topic pub -r 10 /cmd_vel geometry_msgs/msg/Twist "{linear: {x: 0.3, y: 0.0, z: 0.0}, angular: {x: 0.0, y: 0.0, z: 0.0}}"

# Stop publishing with Ctrl+C

# 10. Move the Robot Backward

COMMAND | Continuously publish a backward velocity command to /cmd_vel.
PURPOSE | Moves the robot backward through the ROS 2 autonomous control path.
TERMINALS NEEDED | 2 Terminals

### Terminal 1 - Serial Bridge

# Run the Kiwi serial bridge.

### Terminal 2 - Backward Command

ros2 topic pub -r 10 /cmd_vel geometry_msgs/msg/Twist "{linear: {x: -0.3, y: 0.0, z: 0.0}, angular: {x: 0.0, y: 0.0, z: 0.0}}"

# 11. Move the Robot Left

COMMAND | Continuously publish a leftward holonomic velocity command.
PURPOSE | Moves the robot sideways to the left without rotating first.
TERMINALS NEEDED | 2 Terminals

### Terminal 1 - Serial Bridge

# Run the Kiwi serial bridge.

### Terminal 2 - Left Command

ros2 topic pub -r 10 /cmd_vel geometry_msgs/msg/Twist "{linear: {x: 0.0, y: 0.3, z: 0.0}, angular: {x: 0.0, y: 0.0, z: 0.0}}"

# 12. Move the Robot Right

COMMAND | Continuously publish a rightward holonomic velocity command.
PURPOSE | Moves the robot sideways to the right without changing its orientation.
TERMINALS NEEDED | 2 Terminals

### Terminal 1 - Serial Bridge

# Run the Kiwi serial bridge.

### Terminal 2 - Right Command

ros2 topic pub -r 10 /cmd_vel geometry_msgs/msg/Twist "{linear: {x: 0.0, y: -0.3, z: 0.0}, angular: {x: 0.0, y: 0.0, z: 0.0}}"

# 13. Rotate Counterclockwise

COMMAND | Continuously publish a positive angular velocity command.
PURPOSE | Rotates the robot counterclockwise in place.
TERMINALS NEEDED | 2 Terminals

### Terminal 1 - Serial Bridge

# Run the Kiwi serial bridge.

### Terminal 2 - Rotation Command

ros2 topic pub -r 10 /cmd_vel geometry_msgs/msg/Twist "{linear: {x: 0.0, y: 0.0, z: 0.0}, angular: {x: 0.0, y: 0.0, z: 0.5}}"

# 14. Rotate Clockwise

COMMAND | Continuously publish a negative angular velocity command.
PURPOSE | Rotates the robot clockwise in place.
TERMINALS NEEDED | 2 Terminals

### Terminal 1 - Serial Bridge

# Run the Kiwi serial bridge.

### Terminal 2 - Rotation Command

ros2 topic pub -r 10 /cmd_vel geometry_msgs/msg/Twist "{linear: {x: 0.0, y: 0.0, z: 0.0}, angular: {x: 0.0, y: 0.0, z: -0.5}}"

# 15. Move the Robot Diagonally

COMMAND | Publish X and Y translation commands at the same time.
PURPOSE | Demonstrates holonomic movement by allowing the robot to move diagonally without first rotating.
TERMINALS NEEDED | 2 Terminals

### Terminal 1 - Serial Bridge

# Run the Kiwi serial bridge.

### Terminal 2 - Diagonal Command

ros2 topic pub -r 10 /cmd_vel geometry_msgs/msg/Twist "{linear: {x: 0.3, y: 0.3, z: 0.0}, angular: {x: 0.0, y: 0.0, z: 0.0}}"

# 16. Move and Rotate at the Same Time

COMMAND | Publish translation and rotation simultaneously.
PURPOSE | Demonstrates full holonomic motion by moving the robot while also rotating it.
TERMINALS NEEDED | 2 Terminals

### Terminal 1 - Serial Bridge

# Run the Kiwi serial bridge.

### Terminal 2 - Translate + Rotate

ros2 topic pub -r 10 /cmd_vel geometry_msgs/msg/Twist "{linear: {x: 0.3, y: 0.2, z: 0.0}, angular: {x: 0.0, y: 0.0, z: 0.3}}"

# 17. Stop the Robot

COMMAND | Publish a zero-velocity command.
PURPOSE | Commands all translational and rotational velocities to zero.
TERMINALS NEEDED | 1 Terminal if the serial bridge is already running

### Terminal 1

First stop any repeating ros2 topic pub command with Ctrl+C.

Then run:
ros2 topic pub --once /cmd_vel geometry_msgs/msg/Twist "{linear: {x: 0.0, y: 0.0, z: 0.0}, angular: {x: 0.0, y: 0.0, z: 0.0}}"

# 18. View /cmd_vel Commands

COMMAND | Echo the /cmd_vel topic while another node or terminal publishes movement commands.
PURPOSE | Lets you verify exactly what X, Y, and rotational velocity commands are being sent through ROS 2.
TERMINALS NEEDED | 2 Terminals

### Terminal 1 - Publish Movement

ros2 topic pub -r 10 /cmd_vel geometry_msgs/msg/Twist "{linear: {x: 0.3, y: 0.0, z: 0.0}, angular: {x: 0.0, y: 0.0, z: 0.0}}"

### Terminal 2 - View /cmd_vel

ros2 topic echo /cmd_vel

# 19. View Robot Odometry

COMMAND | Echo the /odom topic.
PURPOSE | Displays the robot's estimated position, orientation, linear velocity, and angular velocity.
TERMINALS NEEDED | 2 Terminals

### Terminal 1 - Serial Bridge / Odometry Node

# Run the node that receives ESP32 odometry telemetry and publishes /odom.

### Terminal 2 - View Odometry

source /opt/ros/lyrical/setup.bash cd ~/robot_ws
source install/setup.bash

ros2 topic echo /odom

# 20. Check Odometry Publishing Rate

COMMAND | Measure how frequently /odom messages are being published.
PURPOSE | Useful for confirming that odometry feedback is updating at the expected rate.
TERMINALS NEEDED | 2 Terminals

### Terminal 1 - Serial Bridge / Odometry Node

# Run the Kiwi serial bridge / odometry node.

### Terminal 2 - Check /odom Rate

ros2 topic hz /odom

# 21. View TF Data

COMMAND | View ROS 2 transforms.
PURPOSE | Used to inspect coordinate-frame relationships such as base_link, odom, LiDAR frames, and other robot links.
TERMINALS NEEDED | 1 Terminal

### Terminal 1

Dynamic transforms:
ros2 topic echo /tf

Static transforms:
ros2 topic echo /tf_static

# 22. View the Robot and LiDAR Together in RViz

COMMAND | Run the LiDAR driver and robot visualization simultaneously.
PURPOSE | Allows the robot model and LiDAR scan data to be viewed together in RViz.

### TERMINALS NEEDED

### 2 Terminals minimum

### Terminal 1 - LiDAR

source /opt/ros/lyrical/setup.bash cd ~/robot_ws
source install/setup.bash

ros2 launch ldlidar_ros2 ld19.launch.py

### Terminal 2 - RViz / Robot Model

source /opt/ros/lyrical/setup.bash cd ~/robot_ws
source install/setup.bash

ros2 launch kiwi_drive_description display.launch.py

# In RViz, add a LaserScan display and set the topic to /scan.

# 23. Full Robot Control Test

COMMAND | Run the serial bridge, LiDAR, RViz, and a movement command at the same time.
PURPOSE | Provides a complete system-level test of Raspberry Pi communication, ROS 2 control, LiDAR, visualization, and robot movement.
TERMINALS NEEDED | 4 Terminals

### Terminal 1 - Serial Bridge

source /opt/ros/lyrical/setup.bash cd ~/robot_ws
source install/setup.bash

# Run the Kiwi serial bridge.

### Terminal 2 - LiDAR

source /opt/ros/lyrical/setup.bash cd ~/robot_ws
source install/setup.bash

ros2 launch ldlidar_ros2 ld19.launch.py

### Terminal 3 - RViz

source /opt/ros/lyrical/setup.bash cd ~/robot_ws
source install/setup.bash

ros2 launch kiwi_drive_description display.launch.py

### Terminal 4 - Movement

source /opt/ros/lyrical/setup.bash cd ~/robot_ws
source install/setup.bash

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

# 24. ESP32 Direct Serial Commands

COMMAND | Send commands directly to the ESP32 serial protocol.
PURPOSE | Useful for testing the ESP32 control layer without going through the full ROS 2 command path.
TERMINALS NEEDED | 1 Serial terminal

### Commands

MODE,AUTO
# Switch ESP32 to autonomous mode.

MODE,MANUAL
# Return control to the Bluetooth controller.

V,x,y,rotation
# Send a normalized movement command.

# Example: V,0.0,1.0,0.0

STOP
# Stop all motors.

PING
# Test serial communication. # Expected response: ACK,PONG

# 25. Check Connected USB Serial Devices

COMMAND | List USB serial devices.
PURPOSE | Useful for identifying which /dev/ttyUSB port belongs to the ESP32 and which belongs to the LiDAR.
TERMINALS NEEDED | 1 Terminal

### Terminal 1

ls /dev/ttyUSB*

Example:
/dev/ttyUSB0
/dev/ttyUSB1

# 26. Quick Troubleshooting Commands

COMMAND | Use common ROS 2 diagnostic commands.
PURPOSE | These commands help identify missing packages, missing nodes/topics, LiDAR problems, odometry issues, and USB device problems.
TERMINALS NEEDED | 1 Terminal for each check

### Common Checks

# Rebuild and re-source workspace cd ~/robot_ws

colcon build --symlink-install source install/setup.bash

# Topics

ros2 topic list

# Nodes

ros2 node list

# LiDAR data

ros2 topic echo /scan

# LiDAR rate

ros2 topic hz /scan

# Velocity commands

ros2 topic echo /cmd_vel

# Odometry

ros2 topic echo /odom

# Odometry rate

ros2 topic hz /odom

# USB serial devices

ls /dev/ttyUSB*

# Important Notes

### 1. Source ROS 2 in Every New Terminal

### Commands

source /opt/ros/lyrical/setup.bash cd ~/robot_ws
source install/setup.bash

### 2. ROS Movement Requires AUTO Mode

The ESP32 must be in AUTO mode before autonomous /cmd_vel commands are accepted.

### 3. Continuous Movement Commands

Commands using ros2 topic pub -r 10 continue publishing until Ctrl+C is pressed.

### 4. Autonomous Command Watchdog

The ESP32 expects repeated autonomous velocity commands. If the Raspberry Pi or ROS 2 stops sending commands for too long, the ESP32 automatically stops all motors.

### 5. Raspberry Pi / ROS 2 Responsibilities

LiDAR, SLAM, navigation, /cmd_vel generation, odometry publishing, and high-level autonomous control.

### 6. ESP32 Responsibilities

Xbox controller, manual/autonomous mode selection, Kiwi-drive inverse kinematics, encoder interrupts, wheel RPM measurement, velocity PID, motor PWM/direction, emergency stop, autonomous watchdog, and odometry telemetry.

### 7. Normal Command Flow

### Command Flow

ROS 2 /cmd_vel
v
Serial Bridge
v
ESP32
v
driveKiwi()
v
Target Wheel RPM
v
Velocity PID
v
Motor PWM

### 8. Feedback Flow

### Feedback Flow

Motor Encoders
v
ESP32
v
Measured Wheel RPM + Encoder Counts |
v
ODOM Serial Telemetry
v
Raspberry Pi
v
ROS 2 /odom

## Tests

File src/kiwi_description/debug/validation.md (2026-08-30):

# Validation Report: Kiwi_Drive_Full_Assembly_Copy_Copy

## Status: PASS (with warnings)

## Summary

| Metric | Value |
|---|---|
| Links | 5 |
| Joints | 4 |
| Assemblies | 17 |
| Root | `base_link` |
| Errors | 0 |
| Warnings | 1 |

## Warnings

- Root link renamed: 'Rear_Base_Plate' → 'base_link' (REP 120 convention). Consider renaming the component to 'base_link' in Fusion.

## Kinematic Tree

```
base_link [BAKE] [primitive]
  └─ wheel_1_to_base_link [continuous]
    wheel_1_link_Omni_Wheel [BAKE] [primitive]
  └─ wheel_2_to_base_link [continuous]
    wheel_2_link_Omni_Wheel [BAKE] [primitive]
  └─ wheel_3_to_base_link [continuous]
    wheel_3_link_Omni_Wheel [BAKE] [primitive]
  └─ base_link_to_lidar_link [fixed]
    Lidar_Mounting_Plate [primitive]
```

## Collision Geometry

| Link | Source | Shape/File |
|---|---|---|
| `Lidar_Mounting_Plate` | primitive STL | box |
| `base_link` | primitive STL | box |
| `wheel_1_link_Omni_Wheel` | primitive STL | box |
| `wheel_2_link_Omni_Wheel` | primitive STL | box |
| `wheel_3_link_Omni_Wheel` | primitive STL | box |

## Mesh Bake Offsets

Links where joint frame ≠ component origin. Visual/inertial/collision origins shifted.

| Link | Offset (mm) |
|---|---|
| `base_link` | (0.0, 0.0, 0.0) |
| `wheel_1_link_Omni_Wheel` | (-88.8, 603.2, 368.0) |
| `wheel_2_link_Omni_Wheel` | (129.4, -595.8, 368.0) |
| `wheel_3_link_Omni_Wheel` | (-89.8, 603.1, 368.0) |

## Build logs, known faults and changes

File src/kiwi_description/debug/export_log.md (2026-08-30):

# Export Log: Kiwi_Drive_Full_Assembly-Copy-Copy

**Generated:** 2026-08-30T14:11:42.542310

```
[14:10:05] fusion2URDF v3.1.0
[14:10:05] Time: 2026-08-30T14:10:05.508442
[14:10:05] Design: Kiwi_Drive_Full_Assembly-Copy-Copy
[14:10:05] Components: 53
[14:10:05] 
=== PHASE 1: EXTRACTION ===
[14:10:05]   Document unit: mm
[14:10:05] 
=== EXTRACTION: OCCURRENCES ===
[14:10:05]   [LEAF] d=1 2020_400mm_Aluminum_Extrusion
[14:10:05]     path: base_link:1+2020_400mm_Aluminum_Extrusion:1
[14:10:05]     global_pos: (-0.180000, -0.129904, -0.000000) m
[14:10:05]     mass: 0.570259 kg, bodies: 1
[14:10:05]     com_global: (-0.180000, 0.050096, 0.000000) m
[14:10:05]     com_component_local: (0.000000, 0.180000, 0.000000) m
[14:10:05]     inertia@origin: ixx=2.610302e-02 iyy=4.636788e-05 izz=2.610302e-02 kg·m²
[14:10:05]     inertia@com:    ixx=7.626636e-03 iyy=4.636788e-05 izz=7.626636e-03 kg·m²
[14:10:05]     material: Steel
[14:10:05]     color: RGB(0.35, 0.35, 0.35) [Paint_Metallic_Black]
[14:10:05]     bbox: (0.0200 x 0.4000 x 0.0200) m
[14:10:05]   [LEAF] d=1 2020_400mm_Aluminum_Extrusion
[14:10:05]     path: base_link:1+2020_400mm_Aluminum_Extrusion:5
[14:10:05]     global_pos: (0.202500, -0.090933, 0.000000) m
[14:10:05]     mass: 0.570259 kg, bodies: 1
[14:10:05]     com_global: (0.202500, 0.089067, 0.000000) m
[14:10:05]     com_component_local: (0.000000, 0.180000, 0.000000) m
[14:10:05]     inertia@origin: ixx=2.610302e-02 iyy=4.636788e-05 izz=2.610302e-02 kg·m²
[14:10:05]     inertia@com:    ixx=7.626636e-03 iyy=4.636788e-05 izz=7.626636e-03 kg·m²
[14:10:05]     material: Steel
[14:10:05]     color: RGB(0.35, 0.35, 0.35) [Paint_Metallic_Black]
[14:10:05]     bbox: (0.0200 x 0.4000 x 0.0200) m
[14:10:05]   [LEAF] d=1 2020_400mm_Aluminum_Extrusion
[14:10:05]     path: base_link:1+2020_400mm_Aluminum_Extrusion:4
[14:10:05]     global_pos: (-0.202500, -0.090933, 0.000000) m
[14:10:05]     mass: 0.570259 kg, bodies: 1
[14:10:05]     com_global: (-0.202500, 0.089067, 0.000000) m
[14:10:05]     com_component_local: (0.000000, 0.180000, 0.000000) m
[14:10:05]     inertia@origin: ixx=2.610302e-02 iyy=4.636788e-05 izz=2.610302e-02 kg·m²
[14:10:05]     inertia@com:    ixx=7.626636e-03 iyy=4.636788e-05 izz=7.626636e-03 kg·m²
[14:10:05]     material: Steel
[14:10:05]     color: RGB(0.35, 0.35, 0.35) [Paint_Metallic_Black]
[14:10:05]     bbox: (0.0200 x 0.4000 x 0.0200) m
[14:10:05]   [LEAF] d=1 2020_400mm_Aluminum_Extrusion
[14:10:05]     path: base_link:1+2020_400mm_Aluminum_Extrusion:7
[14:10:05]     global_pos: (0.202839, -0.117109, 0.041859) m
[14:10:05]     mass: 0.570259 kg, bodies: 1
[14:10:05]     com_global: (0.202839, 0.062891, 0.041859) m
[14:10:05]     com_component_local: (0.000000, 0.180000, 0.000000) m
[14:10:05]     inertia@origin: ixx=2.610302e-02 iyy=4.636788e-05 izz=2.610302e-02 kg·m²
[14:10:05]     inertia@com:    ixx=7.626636e-03 iyy=4.636788e-05 izz=7.626636e-03 kg·m²
[14:10:05]     material: Steel
[14:10:05]     color: RGB(0.35, 0.35, 0.35) [Paint_Metallic_Black]
[14:10:05]     bbox: (0.0200 x 0.4000 x 0.0200) m
[14:10:05]   [LEAF] d=1 2020_400mm_Aluminum_Extrusion
[14:10:05]     path: base_link:1+2020_400mm_Aluminum_Extrusion:8
[14:10:05]     global_pos: (-0.202839, -0.117109, 0.041859) m
[14:10:05]     mass: 0.570259 kg, bodies: 1
[14:10:05]     com_global: (-0.202839, 0.062891, 0.041859) m
[14:10:05]     com_component_local: (0.000000, 0.180000, 0.000000) m
[14:10:05]     inertia@origin: ixx=2.610302e-02 iyy=4.636788e-05 izz=2.610302e-02 kg·m²
[14:10:05]     inertia@com:    ixx=7.626636e-03 iyy=4.636788e-05 izz=7.626636e-03 kg·m²
[14:10:05]     material: Steel
[14:10:05]     color: RGB(0.35, 0.35, 0.35) [Paint_Metallic_Black]
[14:10:05]     bbox: (0.0200 x 0.4000 x 0.0200) m
[14:10:05]   [LEAF] d=1 2020_400mm_Aluminum_Extrusion
[14:10:05]     path: base_link:1+2020_400mm_Aluminum_Extrusion:9
[14:10:05]     global_pos: (0.000000, 0.046452, 0.349013) m
[14:10:05]     mass: 0.570259 kg, bodies: 1
[14:10:05]     com_global: (0.000000, 0.226452, 0.349013) m
[14:10:05]     com_component_local: (0.000000, 0.180000, 0.000000) m
[14:10:05]     inertia@origin: ixx=2.610302e-02 iyy=4.636788e-05 izz=2.610302e-02 kg·m²
[14:10:05]     inertia@com:    ixx=7.626636e-03 iyy=4.636788e-05 izz=7.626636e-03 kg·m²
[14:10:05]     material: Steel
[14:10:05]     color: RGB(0.35, 0.35, 0.35) [Paint_Metallic_Black]
[14:10:05]     bbox: (0.0200 x 0.4000 x 0.0200) m
[14:10:05]   [LEAF] d=1 Top_Plate
[14:10:05]     path: base_link:1+Top_Plate:1
[14:10:05]     global_pos: (0.000000, 0.000000, 0.000000) m
[14:10:05]     mass: 1.175222 kg, bodies: 1
[14:10:05]     com_global: (0.000001, -0.000000, 0.375985) m
[14:10:05]     com_component_local: (0.000001, -0.000000, 0.375985) m
[14:10:05]     inertia@origin: ixx=1.673064e-01 iyy=1.673064e-01 izz=2.197908e-03 kg·m²
[14:10:05]     inertia@com:    ixx=1.171949e-03 iyy=1.171956e-03 izz=2.197908e-03 kg·m²
[14:10:05]     material: Steel
[14:10:05]     color: RGB(0.07, 0.13, 0.50) [ABS_White_1]
[14:10:05]     bbox: (0.1250 x 0.1256 x 0.0480) m
[14:10:05]   [LEAF] d=1 Motor_Mount
[14:10:05]     path: base_link:1+Motor_Mount:1
[14:10:05]     global_pos: (0.000000, 0.000000, 0.000000) m
[14:10:05]     mass: 0.436296 kg, bodies: 1
[14:10:05]     com_global: (0.209969, -0.121243, -0.002628) m
[14:10:05]     com_component_local: (0.209969, -0.121243, -0.002628) m
[14:10:05]     inertia@origin: ixx=6.662523e-03 iyy=1.946299e-02 izz=2.576619e-02 kg·m²
[14:10:05]     inertia@com:    ixx=2.460108e-04 iyy=2.250943e-04 izz=1.178017e-04 kg·m²
[14:10:05]     material: Steel
[14:10:05]     color: RGB(0.07, 0.13, 0.50) [ABS_White_1]
[14:10:05]     bbox: (0.0508 x 0.0565 x 0.0958) m
[14:10:05]   [LEAF] d=1 Motor_Mount
[14:10:05]     path: base_link:1+Motor_Mount:3
[14:10:05]     global_pos: (-0.000000, 0.000000, 0.000000) m
[14:10:05]     mass: 0.436296 kg, bodies: 1
[14:10:05]     com_global: (0.209969, -0.121243, -0.002628) m
[14:10:05]     com_component_local: (0.209969, -0.121243, -0.002628) m
[14:10:05]     inertia@origin: ixx=6.662523e-03 iyy=1.946299e-02 izz=2.576619e-02 kg·m²
[14:10:05]     inertia@com:    ixx=2.460108e-04 iyy=2.250943e-04 izz=1.178017e-04 kg·m²
[14:10:05]     material: Steel
[14:10:05]     color: RGB(0.07, 0.13, 0.50) [ABS_White_1]
[14:10:05]     bbox: (0.0508 x 0.0565 x 0.0958) m
[14:10:05]   [LEAF] d=1 Motor_Mount
[14:10:05]     path: base_link:1+Motor_Mount:2
[14:10:05]     global_pos: (-0.000000, 0.000000, -0.000000) m
[14:10:05]     mass: 0.436296 kg, bodies: 1
[14:10:05]     com_global: (0.209969, -0.121243, -0.002628) m
[14:10:05]     com_component_local: (0.209969, -0.121243, -0.002628) m
[14:10:05]     inertia@origin: ixx=6.662523e-03 iyy=1.946299e-02 izz=2.576619e-02 kg·m²
[14:10:05]     inertia@com:    ixx=2.460108e-04 iyy=2.250943e-04 izz=1.178017e-04 kg·m²
[14:10:05]     material: Steel
[14:10:05]     color: RGB(0.07, 0.13, 0.50) [ABS_White_1]
[14:10:05]     bbox: (0.0508 x 0.0565 x 0.0958) m
[14:10:05]   [LEAF] d=1 Front_Right_Base_Plate
[14:10:05]     path: base_link:1+Front_Right_Base_Plate:1
[14:10:05]     global_pos: (0.000000, 0.000000, 0.000000) m
[14:10:05]     mass: 1.387013 kg, bodies: 1
[14:10:05]     com_global: (-0.096008, -0.055285, 0.013006) m
[14:10:05]     com_component_local: (-0.096008, -0.055285, 0.013006) m
[14:10:05]     inertia@origin: ixx=8.254471e-03 iyy=1.695557e-02 izz=2.473400e-02 kg·m²
[14:10:05]     inertia@com:    ixx=3.780590e-03 iyy=3.936143e-03 izz=7.709962e-03 kg·m²
[14:10:05]     material: Steel
[14:10:05]     color: RGB(1.00, 1.00, 1.00) [Plastic_Translucent_Glossy_White]
[14:10:05]     bbox: (0.2301 x 0.2190 x 0.0054) m
[14:10:05]   [LEAF] d=1 Front_Left_Base_Plate
[14:10:05]     path: base_link:1+Front_Left_Base_Plate:1
[14:10:05]     global_pos: (0.000650, 0.000064, 0.000000) m
[14:10:05]     mass: 1.381733 kg, bodies: 1
[14:10:05]     com_global: (-0.095193, -0.056023, 0.013009) m
[14:10:05]     com_component_local: (-0.095843, -0.056087, 0.013009) m
[14:10:05]     inertia@origin: ixx=8.315368e-03 iyy=1.690035e-02 izz=2.474131e-02 kg·m²
[14:10:05]     inertia@com:    ixx=3.735008e-03 iyy=3.974013e-03 izz=7.702282e-03 kg·m²
[14:10:05]     material: Steel
[14:10:05]     color: RGB(1.00, 1.00, 1.00) [Plastic_Translucent_Glossy_White]
[14:10:05]     bbox: (0.2301 x 0.2190 x 0.0054) m
[14:10:05]   [LEAF] d=1 Rear_Base_Plate
[14:10:05]     path: base_link:1+Rear_Base_Plate:1
[14:10:05]     global_pos: (0.000151, 0.000124, -0.000046) m
[14:10:05]     mass: 1.396297 kg, bodies: 1
[14:10:05]     com_global: (-0.095598, -0.055353, 0.012961) m
[14:10:05]     com_component_local: (-0.095749, -0.055476, 0.013007) m
[14:10:05]     inertia@origin: ixx=8.328051e-03 iyy=1.701441e-02 izz=2.486320e-02 kg·m²
[14:10:05]     inertia@com:    ixx=3.794528e-03 iyy=3.977072e-03 izz=7.764790e-03 kg·m²
[14:10:05]     material: Steel
[14:10:05]     color: RGB(1.00, 1.00, 1.00) [Plastic_Translucent_Glossy_White]
[14:10:05]     bbox: (0.2301 x 0.2190 x 0.0054) m
[14:10:05]   [LEAF] d=4 PinHeader_1x02_P254mm_Vertical
[14:10:05]     path: base_link:1+PCB Housing:1+Main_PCB:1+PinHeader_1x02_P2.54mm_Vertical:1+PinHeader_1x02_P254mm_Vertical:1
[14:10:05]     global_pos: (0.039357, 0.003055, -0.004665) m
[14:10:05]     mass: 0.000309 kg, bodies: 1
[14:10:05]     com_global: (0.039357, 0.001785, -0.003039) m
[14:10:05]     com_component_local: (0.000000, -0.001270, 0.001626) m
[14:10:05]     inertia@origin: ixx=2.995748e-09 iyy=1.998491e-09 izz=1.263268e-09 kg·m²
[14:10:05]     inertia@com:    ixx=1.679855e-09 iyy=1.181226e-09 izz=7.646390e-10 kg·m²
[14:10:05]     material: Steel
[14:10:05]     color: RGB(0.63, 0.63, 0.63) [Steel_Satin]
[14:10:05]     bbox: (0.0025 x 0.0051 x 0.0115) m
[14:10:05]   [SUBASM] d=3 PinHeader_1x02_P2_54mm_Vertical
[14:10:05]     path: base_link:1+PCB Housing:1+Main_PCB:1+PinHeader_1x02_P2.54mm_Vertical:1
[14:10:05]     global_pos: (0.039357, 0.003055, -0.004665) m
[14:10:05]   [LEAF] d=4 PinHeader_1x04_P254mm_Vertical
[14:10:05]     path: base_link:1+PCB Housing:1+Main_PCB:1+PinHeader_1x04_P2.54mm_Vertical:1+PinHeader_1x04_P254mm_Vertical:1
[14:10:05]     global_pos: (-0.010674, 0.022090, -0.004665) m
[14:10:05]     mass: 0.000618 kg, bodies: 1
[14:10:05]     com_global: (-0.010674, 0.018280, -0.003039) m
[14:10:05]     com_component_local: (-0.000000, -0.003810, 0.001626) m
[14:10:05]     inertia@origin: ixx=1.795859e-08 iyy=3.996982e-09 izz=1.449362e-08 kg·m²
[14:10:05]     inertia@com:    ixx=7.348740e-09 iyy=2.362453e-09 izz=5.518308e-09 kg·m²
[14:10:05]     material: Steel
[14:10:05]     color: RGB(0.63, 0.63, 0.63) [Steel_Satin]
[14:10:05]     bbox: (0.0025 x 0.0102 x 0.0115) m
[14:10:05]   [SUBASM] d=3 PinHeader_1x04_P2_54mm_Vertical
[14:10:05]     path: base_link:1+PCB Housing:1+Main_PCB:1+PinHeader_1x04_P2.54mm_Vertical:1
[14:10:05]     global_pos: (-0.010674, 0.022090, -0.004665) m
[14:10:05]   [LEAF] d=4 PinHeader_1x10_P254mm_Vertical
[14:10:05]     path: base_link:1+PCB Housing:1+Main_PCB:1+PinHeader_1x10_P2.54mm_Vertical:1+PinHeader_1x10_P254mm_Vertical:1
[14:10:05]     global_pos: (-0.015578, 0.013485, -0.004665) m
[14:10:05]     mass: 0.001546 kg, bodies: 1
[14:10:05]     com_global: (-0.015578, 0.002055, -0.003039) m
[14:10:05]     com_component_local: (-0.000000, -0.011430, 0.001626) m
[14:10:05]     inertia@origin: ixx=2.942108e-07 iyy=9.992454e-09 izz=2.855484e-07 kg·m²
[14:10:05]     inertia@com:    ixx=8.817987e-08 iyy=5.906132e-09 izz=8.360379e-08 kg·m²
[14:10:05]     material: Steel
[14:10:05]     color: RGB(0.63, 0.63, 0.63) [Steel_Satin]
[14:10:05]     bbox: (0.0025 x 0.0254 x 0.0115) m
[14:10:05]   [SUBASM] d=3 PinHeader_1x10_P2_54mm_Vertical
[14:10:05]     path: base_link:1+PCB Housing:1+Main_PCB:1+PinHeader_1x10_P2.54mm_Vertical:1
[14:10:05]     global_pos: (-0.015578, 0.013485, -0.004665) m
[14:10:05]   [LEAF] d=4 Converter_DCDC_RECOM_R_78E_05_THT
[14:10:05]     path: base_link:1+PCB Housing:1+Main_PCB:1+Converter_DCDC_RECOM_R-78E-0.5_THT:1+Converter_DCDC_RECOM_R_78E_05_THT:1
[14:10:05]     global_pos: (-0.027107, 0.004990, -0.004665) m
[14:10:05]     mass: 0.008053 kg, bodies: 1
[14:10:05]     com_global: (-0.024617, 0.007235, 0.000616) m
[14:10:05]     com_component_local: (0.002490, 0.002245, 0.005281) m
[14:10:05]     inertia@origin: ixx=3.868556e-07 iyy=4.377805e-07 izz=2.286899e-07 kg·m²
[14:10:05]     inertia@com:    ixx=1.216809e-07 iyy=1.632490e-07 izz=1.381790e-07 kg·m²
[14:10:05]     material: Steel
[14:10:05]     color: RGB(0.63, 0.63, 0.63) [Steel_Satin]
[14:10:05]     bbox: (0.0116 x 0.0085 x 0.0145) m
[14:10:05]   [SUBASM] d=3 Converter_DCDC_RECOM_R_78E_0_5_THT
[14:10:05]     path: base_link:1+PCB Housing:1+Main_PCB:1+Converter_DCDC_RECOM_R-78E-0.5_THT:1
[14:10:05]     global_pos: (-0.027107, 0.004990, -0.004665) m
[14:10:05]   [LEAF] d=3 KiwiDrive_PCB
[14:10:05]     path: base_link:1+PCB Housing:1+Main_PCB:1+KiwiDrive_PCB:1
[14:10:05]     global_pos: (-0.000414, -0.174060, -0.006260) m
[14:10:05]     mass: 0.094609 kg, bodies: 1
[14:10:05]     com_global: (0.150138, -0.270474, -0.005505) m
[14:10:05]     com_component_local: (0.150552, -0.096414, 0.000755) m
[14:10:05]     inertia@origin: ixx=9.747146e-04 iyy=2.230191e-03 izz=3.204762e-03 kg·m²
[14:10:05]     inertia@com:    ixx=9.520841e-05 iyy=8.573879e-05 izz=1.809112e-04 kg·m²
[14:10:05]     material: Steel
[14:10:05]     color: RGB(0.96, 0.96, 0.95) [Paint_Enamel_Glossy_White]
[14:10:05]     bbox: (0.1433 x 0.1256 x 0.0015) m
[14:10:05]   [SUBASM] d=2 Main_PCB
[14:10:05]     path: base_link:1+PCB Housing:1+Main_PCB:1
[14:10:05]     global_pos: (-0.000414, -0.174060, -0.006260) m
[14:10:05]   [LEAF] d=2 PCBoutline
[14:10:05]     path: base_link:1+PCB Housing:1+PCBoutline:1
[14:10:05]     global_pos: (-0.000414, -0.174060, -0.006260) m
[14:10:05]     mass: 0.063805 kg, bodies: 1
[14:10:05]     com_global: (0.150162, -0.270503, -0.006761) m
[14:10:05]     com_component_local: (0.150576, -0.096443, -0.000501) m
[14:10:05]     inertia@origin: ixx=6.576142e-04 iyy=1.504544e-03 izz=2.162115e-03 kg·m²
[14:10:05]     inertia@com:    ixx=6.412536e-05 iyy=5.785932e-05 izz=1.219740e-04 kg·m²
[14:10:05]     material: Steel
[14:10:05]     color: RGB(0.63, 0.63, 0.63) [Steel_Satin]
[14:10:05]     bbox: (0.1436 x 0.1259 x 0.0010) m
[14:10:05]   [LEAF] d=2 PCM_Mounting_Enclosure
[14:10:05]     path: base_link:1+PCB Housing:1+PCM_Mounting_Enclosure:1
[14:10:05]     global_pos: (-0.000414, -0.174060, -0.006260) m
[14:10:05]     mass: 0.540107 kg, bodies: 1
[14:10:05]     com_global: (0.150600, -0.271494, -0.002156) m
[14:10:05]     com_component_local: (0.151014, -0.097435, 0.004104) m
[14:10:05]     inertia@origin: ixx=6.091189e-03 iyy=1.326292e-02 izz=1.928943e-02 kg·m²
[14:10:05]     inertia@com:    ixx=9.545625e-04 iyy=9.365158e-04 izz=1.844596e-03 kg·m²
[14:10:05]     material: Steel
[14:10:05]     color: RGB(0.63, 0.63, 0.63) [Steel_Satin]
[14:10:05]     bbox: (0.1601 x 0.1404 x 0.0215) m
[14:10:05]   [SUBASM] d=1 PCB_Housing
[14:10:05]     path: base_link:1+PCB Housing:1
[14:10:05]     global_pos: (-0.000414, -0.174060, -0.006260) m
[14:10:05]   [LEAF] d=2 Battery_Mount_Front
[14:10:05]     path: base_link:1+Battery_Mount_Assembly:1+Battery_Mount_Front:1
[14:10:05]     global_pos: (-0.070000, -0.080000, -0.020750) m
[14:10:05]     mass: 0.106316 kg, bodies: 1
[14:10:05]     com_global: (-0.070000, -0.070000, -0.010765) m
[14:10:05]     com_component_local: (0.000000, 0.010000, 0.009985) m
[14:10:05]     inertia@origin: ixx=4.194555e-05 iyy=8.455186e-05 izz=7.094471e-05 kg·m²
[14:10:05]     inertia@com:    ixx=2.071423e-05 iyy=7.395215e-05 izz=6.031311e-05 kg·m²
[14:10:05]     material: Steel
[14:10:05]     color: RGB(0.63, 0.63, 0.63) [Steel_Satin]
[14:10:05]     bbox: (0.0750 x 0.0200 x 0.0360) m
[14:10:05]   [LEAF] d=2 Battery_Mount_Back
[14:10:05]     path: base_link:1+Battery_Mount_Assembly:1+Battery_Mount_Back:1
[14:10:05]     global_pos: (-0.125000, -0.080000, -0.020750) m
[14:10:05]     mass: 0.155165 kg, bodies: 1
[14:10:05]     com_global: (-0.125000, -0.066381, -0.009590) m
[14:10:05]     com_component_local: (0.000000, 0.013619, 0.011160) m
[14:10:05]     inertia@origin: ixx=7.929481e-05 iyy=1.133706e-04 izz=1.076353e-04 kg·m²
[14:10:05]     inertia@com:    ixx=3.118676e-05 iyy=9.404404e-05 izz=7.885380e-05 kg·m²
[14:10:05]     material: Steel
[14:10:05]     color: RGB(0.63, 0.63, 0.63) [Steel_Satin]
[14:10:05]     bbox: (0.0750 x 0.0230 x 0.0360) m
[14:10:05]   [SUBASM] d=1 Battery_Mount_Assembly
[14:10:05]     path: base_link:1+Battery_Mount_Assembly:1
[14:10:05]     global_pos: (-0.070000, -0.080000, -0.020750) m
[14:10:05]   [LEAF] d=1 2020_Aluminum_Extrusion_Mounting_Spacer
[14:10:05]     path: base_link:1+2020_Aluminum_Extrusion_Mounting_Spacer:1
[14:10:05]     global_pos: (0.000000, 0.000000, 0.000000) m
[14:10:05]     mass: 0.037605 kg, bodies: 1
[14:10:05]     com_global: (0.167312, -0.029986, 0.006108) m
[14:10:05]     com_component_local: (0.167312, -0.029986, 0.006108) m
[14:10:05]     inertia@origin: ixx=1.120928e-04 iyy=1.079906e-03 izz=1.189125e-03 kg·m²
[14:10:05]     inertia@com:    ixx=7.687634e-05 iyy=2.579536e-05 izz=1.026034e-04 kg·m²
[14:10:05]     material: Steel
[14:10:05]     color: RGB(0.63, 0.63, 0.63) [Steel_Satin]
[14:10:05]     bbox: (0.0995 x 0.1618 x 0.0035) m
[14:10:05]   [LEAF] d=1 JGA25_370DC_Motor
[14:10:05]     path: base_link:1+JGA25-370DC_Motor:1
[14:10:05]     global_pos: (0.184042, -0.106257, -0.028962) m
[14:10:05]     mass: 0.204417 kg, bodies: 1
[14:10:05]     com_global: (0.200606, -0.106257, -0.028962) m
[14:10:05]     com_component_local: (0.016564, -0.000001, 0.000000) m
[14:10:05]     inertia@origin: ixx=1.523969e-05 iyy=1.164318e-04 izz=1.164264e-04 kg·m²
[14:10:05]     inertia@com:    ixx=1.523969e-05 iyy=6.034839e-05 izz=6.034290e-05 kg·m²
[14:10:05]     material: Steel
[14:10:05]     color: RGB(0.63, 0.63, 0.63) [Steel_Satin]
[14:10:05]     bbox: (0.0705 x 0.0252 x 0.0252) m
[14:10:05]   [LEAF] d=1 JGA25_370DC_Motor
[14:10:05]     path: base_link:1+JGA25-370DC_Motor:3
[14:10:05]     global_pos: (-0.000000, 0.212513, -0.028962) m
[14:10:05]     mass: 0.204417 kg, bodies: 1
[14:10:05]     com_global: (0.016564, 0.212513, -0.028962) m
[14:10:05]     com_component_local: (0.016564, -0.000001, 0.000000) m
[14:10:05]     inertia@origin: ixx=1.523969e-05 iyy=1.164318e-04 izz=1.164264e-04 kg·m²
[14:10:05]     inertia@com:    ixx=1.523969e-05 iyy=6.034839e-05 izz=6.034290e-05 kg·m²
[14:10:05]     material: Steel
[14:10:05]     color: RGB(0.63, 0.63, 0.63) [Steel_Satin]
[14:10:05]     bbox: (0.0705 x 0.0252 x 0.0252) m
[14:10:05]   [LEAF] d=1 JGA25_370DC_Motor
[14:10:05]     path: base_link:1+JGA25-370DC_Motor:2
[14:10:05]     global_pos: (-0.184042, -0.106257, -0.028962) m
[14:10:05]     mass: 0.204417 kg, bodies: 1
[14:10:05]     com_global: (-0.167478, -0.106257, -0.028962) m
[14:10:05]     com_component_local: (0.016564, -0.000001, 0.000000) m
[14:10:05]     inertia@origin: ixx=1.523969e-05 iyy=1.164318e-04 izz=1.164264e-04 kg·m²
[14:10:05]     inertia@com:    ixx=1.523969e-05 iyy=6.034839e-05 izz=6.034290e-05 kg·m²
[14:10:05]     material: Steel
[14:10:05]     color: RGB(0.63, 0.63, 0.63) [Steel_Satin]
[14:10:05]     bbox: (0.0705 x 0.0252 x 0.0252) m
[14:10:05]   [SUBASM] d=0 base_link
[14:10:05]     path: base_link:1
[14:10:05]     global_pos: (0.000000, 0.000000, 0.000000) m
[14:10:05]   [LEAF] d=5 F2
[14:10:05]     path: wheel_1_link:1+Wheel_Hub:2+OmniWheelwithHub:1+Omni Wheel:1+A1_ASM:1+F2:1
[14:10:05]     global_pos: (0.264734, -0.152844, -0.028962) m
[14:10:05]     mass: 0.021208 kg, bodies: 1
[14:10:05]     com_global: (0.264765, -0.152844, -0.040323) m
[14:10:05]     com_component_local: (0.000030, 0.000000, -0.011361) m
[14:10:05]     inertia@origin: ixx=1.263883e-05 iyy=1.263752e-05 izz=1.962197e-05 kg·m²
[14:10:05]     inertia@com:    ixx=9.901373e-06 iyy=9.900039e-06 izz=1.962195e-05 kg·m²
[14:10:05]     material: Generic
[14:10:05]     color: RGB(0.75, 0.75, 0.75) [Opaque_191_191_191]
[14:10:05]     bbox: (0.0945 x 0.0933 x 0.0100) m
[14:10:05]   [LEAF] d=5 F5
[14:10:05]     path: wheel_1_link:1+Wheel_Hub:2+OmniWheelwithHub:1+Omni Wheel:1+A1_ASM:1+F5:1
[14:10:05]     global_pos: (0.264734, -0.152844, -0.028962) m
[14:10:05]     mass: 0.004761 kg, bodies: 1
[14:10:05]     com_global: (0.264734, -0.111344, -0.036962) m
[14:10:05]     com_component_local: (-0.000000, 0.041500, -0.008000) m
[14:10:05]     inertia@origin: ixx=8.717993e-06 iyy=5.403131e-07 izz=8.434997e-06 kg·m²
[14:10:05]     inertia@com:    ixx=2.138575e-07 iyy=2.355876e-07 izz=2.355876e-07 kg·m²
[14:10:05]     material: Generic
[14:10:05]     color: RGB(0.75, 0.75, 0.75) [Opaque_191_191_191]
[14:10:05]     bbox: (0.0185 x 0.0190 x 0.0190) m
[14:10:05]   [LEAF] d=5 F6
[14:10:05]     path: wheel_1_link:1+Wheel_Hub:2+OmniWheelwithHub:1+Omni Wheel:1+A1_ASM:1+F6:1
[14:10:05]     global_pos: (0.264734, -0.152844, -0.028962) m
[14:10:05]     mass: 0.000177 kg, bodies: 2
[14:10:05]     com_global: (0.264734, -0.111344, -0.036962) m
[14:10:05]     com_component_local: (0.000000, 0.041500, -0.008000) m
[14:10:05]     inertia@origin: ixx=3.169158e-07 iyy=2.075227e-08 izz=3.147727e-07 kg·m²
[14:10:05]     inertia@com:    ixx=1.976377e-10 iyy=9.403421e-09 izz=9.403421e-09 kg·m²
[14:10:05]     material: Generic
[14:10:05]     color: RGB(0.31, 0.31, 0.31) [Default]
[14:10:05]     bbox: (0.0320 x 0.0035 x 0.0030) m
[14:10:05]   [LEAF] d=5 F5
[14:10:05]     path: wheel_1_link:1+Wheel_Hub:2+OmniWheelwithHub:1+Omni Wheel:1+A1_ASM:1+F5:2
[14:10:05]     global_pos: (0.264734, -0.152844, -0.028962) m
[14:10:05]     mass: 0.004761 kg, bodies: 1
[14:10:05]     com_global: (0.264734, -0.111344, -0.036962) m
[14:10:05]     com_component_local: (-0.000000, 0.041500, -0.008000) m
[14:10:05]     inertia@origin: ixx=8.717993e-06 iyy=5.403131e-07 izz=8.434997e-06 kg·m²
[14:10:05]     inertia@com:    ixx=2.138575e-07 iyy=2.355876e-07 izz=2.355876e-07 kg·m²
[14:10:05]     material: Generic
[14:10:05]     color: RGB(0.75, 0.75, 0.75) [Opaque_191_191_191]
[14:10:05]     bbox: (0.0185 x 0.0190 x 0.0190) m
[14:10:05]   [LEAF] d=5 F6
[14:10:05]     path: wheel_1_link:1+Wheel_Hub:2+OmniWheelwithHub:1+Omni Wheel:1+A1_ASM:1+F6:2
[14:10:05]     global_pos: (0.264734, -0.152844, -0.028962) m
[14:10:05]     mass: 0.000177 kg, bodies: 2
[14:10:05]     com_global: (0.264734, -0.111344, -0.036962) m
[14:10:05]     com_component_local: (0.000000, 0.041500, -0.008000) m
[14:10:05]     inertia@origin: ixx=3.169158e-07 iyy=2.075227e-08 izz=3.147727e-07 kg·m²
[14:10:05]     inertia@com:    ixx=1.976377e-10 iyy=9.403421e-09 izz=9.403421e-09 kg·m²
[14:10:05]     material: Generic
[14:10:05]     color: RGB(0.31, 0.31, 0.31) [Default]
[14:10:05]     bbox: (0.0320 x 0.0035 x 0.0030) m
[14:10:05]   [LEAF] d=5 F5
[14:10:05]     path: wheel_1_link:1+Wheel_Hub:2+OmniWheelwithHub:1+Omni Wheel:1+A1_ASM:1+F5:3
[14:10:05]     global_pos: (0.264734, -0.152844, -0.028962) m
[14:10:05]     mass: 0.004761 kg, bodies: 1
[14:10:05]     com_global: (0.264734, -0.111344, -0.036962) m
[14:10:05]     com_component_local: (-0.000000, 0.041500, -0.008000) m
[14:10:05]     inertia@origin: ixx=8.717993e-06 iyy=5.403131e-07 izz=8.434997e-06 kg·m²
[14:10:05]     inertia@com:    ixx=2.138575e-07 iyy=2.355876e-07 izz=2.355876e-07 kg·m²
[14:10:05]     material: Generic
[14:10:05]     color: RGB(0.75, 0.75, 0.75) [Opaque_191_191_191]
[14:10:05]     bbox: (0.0185 x 0.0190 x 0.0190) m
[14:10:05]   [LEAF] d=5 F6
[14:10:05]     path: wheel_1_link:1+Wheel_Hub:2+OmniWheelwithHub:1+Omni Wheel:1+A1_ASM:1+F6:3
[14:10:05]     global_pos: (0.264734, -0.152844, -0.028962) m
[14:10:05]     mass: 0.000177 kg, bodies: 2
[14:10:05]     com_global: (0.264734, -0.111344, -0.036962) m
[14:10:05]     com_component_local: (0.000000, 0.041500, -0.008000) m
[14:10:05]     inertia@origin: ixx=3.169158e-07 iyy=2.075227e-08 izz=3.147727e-07 kg·m²
[14:10:05]     inertia@com:    ixx=1.976377e-10 iyy=9.403421e-09 izz=9.403421e-09 kg·m²
[14:10:05]     material: Generic
[14:10:05]     color: RGB(0.31, 0.31, 0.31) [Default]
[14:10:05]     bbox: (0.0320 x 0.0035 x 0.0030) m
[14:10:05]   [LEAF] d=5 F5
[14:10:05]     path: wheel_1_link:1+Wheel_Hub:2+OmniWheelwithHub:1+Omni Wheel:1+A1_ASM:1+F5:4
[14:10:05]     global_pos: (0.264734, -0.152844, -0.028962) m
[14:10:05]     mass: 0.004761 kg, bodies: 1
[14:10:05]     com_global: (0.264734, -0.111344, -0.036962) m
[14:10:05]     com_component_local: (-0.000000, 0.041500, -0.008000) m
[14:10:05]     inertia@origin: ixx=8.717993e-06 iyy=5.403131e-07 izz=8.434997e-06 kg·m²
[14:10:05]     inertia@com:    ixx=2.138575e-07 iyy=2.355876e-07 izz=2.355876e-07 kg·m²
[14:10:05]     material: Generic
[14:10:05]     color: RGB(0.75, 0.75, 0.75) [Opaque_191_191_191]
[14:10:05]     bbox: (0.0185 x 0.0190 x 0.0190) m
[14:10:05]   [LEAF] d=5 F6
[14:10:05]     path: wheel_1_link:1+Wheel_Hub:2+OmniWheelwithHub:1+Omni Wheel:1+A1_ASM:1+F6:4
[14:10:05]     global_pos: (0.264734, -0.152844, -0.028962) m
[14:10:05]     mass: 0.000177 kg, bodies: 2
[14:10:05]     com_global: (0.264734, -0.111344, -0.036962) m
[14:10:05]     com_component_local: (0.000000, 0.041500, -0.008000) m
[14:10:05]     inertia@origin: ixx=3.169158e-07 iyy=2.075227e-08 izz=3.147727e-07 kg·m²
[14:10:05]     inertia@com:    ixx=1.976377e-10 iyy=9.403421e-09 izz=9.403421e-09 kg·m²
[14:10:05]     material: Generic
[14:10:05]     color: RGB(0.31, 0.31, 0.31) [Default]
[14:10:05]     bbox: (0.0320 x 0.0035 x 0.0030) m
[14:10:05]   [LEAF] d=5 F5
[14:10:05]     path: wheel_1_link:1+Wheel_Hub:2+OmniWheelwithHub:1+Omni Wheel:1+A1_ASM:1+F5:5
[14:10:05]     global_pos: (0.264734, -0.152844, -0.028962) m
[14:10:05]     mass: 0.004761 kg, bodies: 1
[14:10:05]     com_global: (0.264734, -0.111344, -0.036962) m
[14:10:05]     com_component_local: (-0.000000, 0.041500, -0.008000) m
[14:10:05]     inertia@origin: ixx=8.717993e-06 iyy=5.403131e-07 izz=8.434997e-06 kg·m²
[14:10:05]     inertia@com:    ixx=2.138575e-07 iyy=2.355876e-07 izz=2.355876e-07 kg·m²
[14:10:05]     material: Generic
[14:10:05]     color: RGB(0.75, 0.75, 0.75) [Opaque_191_191_191]
[14:10:05]     bbox: (0.0185 x 0.0190 x 0.0190) m
[14:10:05]   [LEAF] d=5 F6
[14:10:05]     path: wheel_1_link:1+Wheel_Hub:2+OmniWheelwithHub:1+Omni Wheel:1+A1_ASM:1+F6:5
[14:10:05]     global_pos: (0.264734, -0.152844, -0.028962) m
[14:10:05]     mass: 0.000177 kg, bodies: 2
[14:10:05]     com_global: (0.264734, -0.111344, -0.036962) m
[14:10:05]     com_component_local: (0.000000, 0.041500, -0.008000) m
[14:10:05]     inertia@origin: ixx=3.169158e-07 iyy=2.075227e-08 izz=3.147727e-07 kg·m²
[14:10:05]     inertia@com:    ixx=1.976377e-10 iyy=9.403421e-09 izz=9.403421e-09 kg·m²
[14:10:05]     material: Generic
[14:10:05]     color: RGB(0.31, 0.31, 0.31) [Default]
[14:10:05]     bbox: (0.0320 x 0.0035 x 0.0030) m
[14:10:05]   [LEAF] d=5 F5
[14:10:05]     path: wheel_1_link:1+Wheel_Hub:2+OmniWheelwithHub:1+Omni Wheel:1+A1_ASM:1+F5:6
[14:10:05]     global_pos: (0.264734, -0.152844, -0.028962) m
[14:10:05]     mass: 0.004761 kg, bodies: 1
[14:10:05]     com_global: (0.264734, -0.111344, -0.036962) m
[14:10:05]     com_component_local: (-0.000000, 0.041500, -0.008000) m
[14:10:05]     inertia@origin: ixx=8.717993e-06 iyy=5.403131e-07 izz=8.434997e-06 kg·m²
[14:10:05]     inertia@com:    ixx=2.138575e-07 iyy=2.355876e-07 izz=2.355876e-07 kg·m²
[14:10:05]     material: Generic
[14:10:05]     color: RGB(0.75, 0.75, 0.75) [Opaque_191_191_191]
[14:10:05]     bbox: (0.0185 x 0.0190 x 0.0190) m
[14:10:05]   [LEAF] d=5 F6
[14:10:05]     path: wheel_1_link:1+Wheel_Hub:2+OmniWheelwithHub:1+Omni Wheel:1+A1_ASM:1+F6:6
[14:10:05]     global_pos: (0.264734, -0.152844, -0.028962) m
[14:10:05]     mass: 0.000177 kg, bodies: 2
[14:10:05]     com_global: (0.264734, -0.111344, -0.036962) m
[14:10:05]     com_component_local: (0.000000, 0.041500, -0.008000) m
[14:10:05]     inertia@origin: ixx=3.169158e-07 iyy=2.075227e-08 izz=3.147727e-07 kg·m²
[14:10:05]     inertia@com:    ixx=1.976377e-10 iyy=9.403421e-09 izz=9.403421e-09 kg·m²
[14:10:05]     material: Generic
[14:10:05]     color: RGB(0.31, 0.31, 0.31) [Default]
[14:10:05]     bbox: (0.0320 x 0.0035 x 0.0030) m
[14:10:05]   [LEAF] d=5 F5
[14:10:05]     path: wheel_1_link:1+Wheel_Hub:2+OmniWheelwithHub:1+Omni Wheel:1+A1_ASM:1+F5:7
[14:10:05]     global_pos: (0.264734, -0.152844, -0.028962) m
[14:10:05]     mass: 0.004761 kg, bodies: 1
[14:10:05]     com_global: (0.264734, -0.111344, -0.036962) m
[14:10:05]     com_component_local: (-0.000000, 0.041500, -0.008000) m
[14:10:05]     inertia@origin: ixx=8.717993e-06 iyy=5.403131e-07 izz=8.434997e-06 kg·m²
[14:10:05]     inertia@com:    ixx=2.138575e-07 iyy=2.355876e-07 izz=2.355876e-07 kg·m²
[14:10:05]     material: Generic
[14:10:05]     color: RGB(0.75, 0.75, 0.75) [Opaque_191_191_191]
[14:10:05]     bbox: (0.0185 x 0.0190 x 0.0190) m
[14:10:05]   [LEAF] d=5 F6
[14:10:05]     path: wheel_1_link:1+Wheel_Hub:2+OmniWheelwithHub:1+Omni Wheel:1+A1_ASM:1+F6:7
[14:10:05]     global_pos: (0.264734, -0.152844, -0.028962) m
[14:10:05]     mass: 0.000177 kg, bodies: 2
[14:10:05]     com_global: (0.264734, -0.111344, -0.036962) m
[14:10:05]     com_component_local: (0.000000, 0.041500, -0.008000) m
[14:10:05]     inertia@origin: ixx=3.169158e-07 iyy=2.075227e-08 izz=3.147727e-07 kg·m²
[14:10:05]     inertia@com:    ixx=1.976377e-10 iyy=9.403421e-09 izz=9.403421e-09 kg·m²
[14:10:05]     material: Generic
[14:10:05]     color: RGB(0.31, 0.31, 0.31) [Default]
[14:10:05]     bbox: (0.0320 x 0.0035 x 0.0030) m
[14:10:05]   [LEAF] d=5 F5
[14:10:05]     path: wheel_1_link:1+Wheel_Hub:2+OmniWheelwithHub:1+Omni Wheel:1+A1_ASM:1+F5:8
[14:10:05]     global_pos: (0.264734, -0.152844, -0.028962) m
[14:10:05]     mass: 0.004761 kg, bodies: 1
[14:10:05]     com_global: (0.264734, -0.111344, -0.036962) m
[14:10:05]     com_component_local: (-0.000000, 0.041500, -0.008000) m
[14:10:05]     inertia@origin: ixx=8.717993e-06 iyy=5.403131e-07 izz=8.434997e-06 kg·m²
[14:10:05]     inertia@com:    ixx=2.138575e-07 iyy=2.355876e-07 izz=2.355876e-07 kg·m²
[14:10:05]     material: Generic
[14:10:05]     color: RGB(0.75, 0.75, 0.75) [Opaque_191_191_191]
[14:10:05]     bbox: (0.0185 x 0.0190 x 0.0190) m
[14:10:05]   [LEAF] d=5 F6
[14:10:05]     path: wheel_1_link:1+Wheel_Hub:2+OmniWheelwithHub:1+Omni Wheel:1+A1_ASM:1+F6:8
[14:10:05]     global_pos: (0.264734, -0.152844, -0.028962) m
[14:10:05]     mass: 0.000177 kg, bodies: 2
[14:10:05]     com_global: (0.264734, -0.111344, -0.036962) m
[14:10:05]     com_component_local: (0.000000, 0.041500, -0.008000) m
[14:10:05]     inertia@origin: ixx=3.169158e-07 iyy=2.075227e-08 izz=3.147727e-07 kg·m²
[14:10:05]     inertia@com:    ixx=1.976377e-10 iyy=9.403421e-09 izz=9.403421e-09 kg·m²
[14:10:05]     material: Generic
[14:10:05]     color: RGB(0.31, 0.31, 0.31) [Default]
[14:10:05]     bbox: (0.0320 x 0.0035 x 0.0030) m
[14:10:05]   [LEAF] d=5 F5
[14:10:05]     path: wheel_1_link:1+Wheel_Hub:2+OmniWheelwithHub:1+Omni Wheel:1+A1_ASM:1+F5:9
[14:10:05]     global_pos: (0.264734, -0.152844, -0.028962) m
[14:10:05]     mass: 0.004761 kg, bodies: 1
[14:10:05]     com_global: (0.264734, -0.111344, -0.036962) m
[14:10:05]     com_component_local: (-0.000000, 0.041500, -0.008000) m
[14:10:05]     inertia@origin: ixx=8.717993e-06 iyy=5.403131e-07 izz=8.434997e-06 kg·m²
[14:10:05]     inertia@com:    ixx=2.138575e-07 iyy=2.355876e-07 izz=2.355876e-07 kg·m²
[14:10:05]     material: Generic
[14:10:05]     color: RGB(0.75, 0.75, 0.75) [Opaque_191_191_191]
[14:10:05]     bbox: (0.0185 x 0.0190 x 0.0190) m
[14:10:05]   [LEAF] d=5 F6
[14:10:05]     path: wheel_1_link:1+Wheel_Hub:2+OmniWheelwithHub:1+Omni Wheel:1+A1_ASM:1+F6:9
[14:10:05]     global_pos: (0.264734, -0.152844, -0.028962) m
[14:10:05]     mass: 0.000177 kg, bodies: 2
[14:10:05]     com_global: (0.264734, -0.111344, -0.036962) m
[14:10:05]     com_component_local: (0.000000, 0.041500, -0.008000) m
[14:10:05]     inertia@origin: ixx=3.169158e-07 iyy=2.075227e-08 izz=3.147727e-07 kg·m²
[14:10:05]     inertia@com:    ixx=1.976377e-10 iyy=9.403421e-09 izz=9.403421e-09 kg·m²
[14:10:05]     material: Generic
[14:10:05]     color: RGB(0.31, 0.31, 0.31) [Default]
[14:10:05]     bbox: (0.0320 x 0.0035 x 0.0030) m
[14:10:05]   [LEAF] d=5 F2
[14:10:05]     path: wheel_1_link:1+Wheel_Hub:2+OmniWheelwithHub:1+Omni Wheel:1+A1_ASM:1+F2:2
[14:10:05]     global_pos: (0.250877, -0.144844, -0.028962) m
[14:10:05]     mass: 0.021208 kg, bodies: 1
[14:10:05]     com_global: (0.250908, -0.144844, -0.040323) m
[14:10:05]     com_component_local: (0.000030, 0.000000, -0.011361) m
[14:10:05]     inertia@origin: ixx=1.263883e-05 iyy=1.263752e-05 izz=1.962197e-05 kg·m²
[14:10:05]     inertia@com:    ixx=9.901373e-06 iyy=9.900039e-06 izz=1.962195e-05 kg·m²
[14:10:05]     material: Generic
[14:10:05]     color: RGB(0.75, 0.75, 0.75) [Opaque_191_191_191]
[14:10:05]     bbox: (0.0945 x 0.0933 x 0.0100) m
[14:10:05]   [SUBASM] d=4 A1_ASM
[14:10:05]     path: wheel_1_link:1+Wheel_Hub:2+OmniWheelwithHub:1+Omni Wheel:1+A1_ASM:1
[14:10:05]     global_pos: (0.264734, -0.152844, -0.028962) m
[14:10:05]   [LEAF] d=4 F12
[14:10:05]     path: wheel_1_link:1+Wheel_Hub:2+OmniWheelwithHub:1+Omni Wheel:1+F12:1
[14:10:05]     global_pos: (0.264734, -0.152844, -0.028962) m
[14:10:05]     mass: 0.012397 kg, bodies: 1
[14:10:05]     com_global: (0.264734, -0.152844, -0.046210) m
[14:10:05]     com_component_local: (0.000000, -0.000000, -0.017248) m
[14:10:05]     inertia@origin: ixx=6.165417e-06 iyy=6.165417e-06 izz=4.749610e-06 kg·m²
[14:10:05]     inertia@com:    ixx=2.477412e-06 iyy=2.477413e-06 izz=4.749610e-06 kg·m²
[14:10:05]     material: Generic
[14:10:05]     color: RGB(0.75, 0.75, 0.75) [Opaque_191_191_191]
[14:10:05]     bbox: (0.0567 x 0.0567 x 0.0134) m
[14:10:05]   [LEAF] d=5 F2
[14:10:05]     path: wheel_1_link:1+Wheel_Hub:2+OmniWheelwithHub:1+Omni Wheel:1+A1_ASM:2+F2:1
[14:10:05]     global_pos: (0.233210, -0.134644, -0.028962) m
[14:10:05]     mass: 0.021208 kg, bodies: 1
[14:10:05]     com_global: (0.233240, -0.134644, -0.040323) m
[14:10:05]     com_component_local: (0.000030, 0.000000, -0.011361) m
[14:10:05]     inertia@origin: ixx=1.263883e-05 iyy=1.263752e-05 izz=1.962197e-05 kg·m²
[14:10:05]     inertia@com:    ixx=9.901373e-06 iyy=9.900039e-06 izz=1.962195e-05 kg·m²
[14:10:05]     material: Generic
[14:10:05]     color: RGB(0.75, 0.75, 0.75) [Opaque_191_191_191]
[14:10:05]     bbox: (0.0945 x 0.0933 x 0.0100) m
[14:10:05]   [LEAF] d=5 F5
[14:10:05]     path: wheel_1_link:1+Wheel_Hub:2+OmniWheelwithHub:1+Omni Wheel:1+A1_ASM:2+F5:1
[14:10:05]     global_pos: (0.233210, -0.134644, -0.028962) m
[14:10:05]     mass: 0.004761 kg, bodies: 1
[14:10:05]     com_global: (0.233210, -0.093144, -0.036962) m
[14:10:05]     com_component_local: (-0.000000, 0.041500, -0.008000) m
[14:10:05]     inertia@origin: ixx=8.717993e-06 iyy=5.403131e-07 izz=8.434997e-06 kg·m²
[14:10:05]     inertia@com:    ixx=2.138575e-07 iyy=2.355876e-07 izz=2.355876e-07 kg·m²
[14:10:05]     material: Generic
[14:10:05]     color: RGB(0.75, 0.75, 0.75) [Opaque_191_191_191]
[14:10:05]     bbox: (0.0185 x 0.0190 x 0.0190) m
[14:10:05]   [LEAF] d=5 F6
[14:10:05]     path: wheel_1_link:1+Wheel_Hub:2+OmniWheelwithHub:1+Omni Wheel:1+A1_ASM:2+F6:1
[14:10:05]     global_pos: (0.233210, -0.134644, -0.028962) m
[14:10:05]     mass: 0.000177 kg, bodies: 2
[14:10:05]     com_global: (0.233210, -0.093144, -0.036962) m
[14:10:05]     com_component_local: (0.000000, 0.041500, -0.008000) m
[14:10:05]     inertia@origin: ixx=3.169158e-07 iyy=2.075227e-08 izz=3.147727e-07 kg·m²
[14:10:05]     inertia@com:    ixx=1.976377e-10 iyy=9.403421e-09 izz=9.403421e-09 kg·m²
[14:10:05]     material: Generic
[14:10:05]     color: RGB(0.31, 0.31, 0.31) [Default]
[14:10:05]     bbox: (0.0320 x 0.0035 x 0.0030) m
[14:10:05]   [LEAF] d=5 F5
[14:10:05]     path: wheel_1_link:1+Wheel_Hub:2+OmniWheelwithHub:1+Omni Wheel:1+A1_ASM:2+F5:2
[14:10:05]     global_pos: (0.233210, -0.134644, -0.028962) m
[14:10:05]     mass: 0.004761 kg, bodies: 1
[14:10:05]     com_global: (0.233210, -0.093144, -0.036962) m
[14:10:05]     com_component_local: (-0.000000, 0.041500, -0.008000) m
[14:10:05]     inertia@origin: ixx=8.717993e-06 iyy=5.403131e-07 izz=8.434997e-06 kg·m²
[14:10:05]     inertia@com:    ixx=2.138575e-07 iyy=2.355876e-07 izz=2.355876e-07 kg·m²
[14:10:05]     material: Generic
[14:10:05]     color: RGB(0.75, 0.75, 0.75) [Opaque_191_191_191]
[14:10:05]     bbox: (0.0185 x 0.0190 x 0.0190) m
[14:10:05]   [LEAF] d=5 F6
[14:10:05]     path: wheel_1_link:1+Wheel_Hub:2+OmniWheelwithHub:1+Omni Wheel:1+A1_ASM:2+F6:2
[14:10:05]     global_pos: (0.233210, -0.134644, -0.028962) m
[14:10:05]     mass: 0.000177 kg, bodies: 2
[14:10:05]     com_global: (0.233210, -0.093144, -0.036962) m
[14:10:05]     com_component_local: (0.000000, 0.041500, -0.008000) m
[14:10:05]     inertia@origin: ixx=3.169158e-07 iyy=2.075227e-08 izz=3.147727e-07 kg·m²
[14:10:05]     inertia@com:    ixx=1.976377e-10 iyy=9.403421e-09 izz=9.403421e-09 kg·m²
[14:10:05]     material: Generic
[14:10:05]     color: RGB(0.31, 0.31, 0.31) [Default]
[14:10:05]     bbox: (0.0320 x 0.0035 x 0.0030) m
[14:10:05]   [LEAF] d=5 F5
[14:10:05]     path: wheel_1_link:1+Wheel_Hub:2+OmniWheelwithHub:1+Omni Wheel:1+A1_ASM:2+F5:3
[14:10:05]     global_pos: (0.233210, -0.134644, -0.028962) m
[14:10:05]     mass: 0.004761 kg, bodies: 1
[14:10:05]     com_global: (0.233210, -0.093144, -0.036962) m
[14:10:05]     com_component_local: (-0.000000, 0.041500, -0.008000) m
[14:10:05]     inertia@origin: ixx=8.717993e-06 iyy=5.403131e-07 izz=8.434997e-06 kg·m²
[14:10:05]     inertia@com:    ixx=2.138575e-07 iyy=2.355876e-07 izz=2.355876e-07 kg·m²
[14:10:05]     material: Generic
[14:10:05]     color: RGB(0.75, 0.75, 0.75) [Opaque_191_191_191]
[14:10:05]     bbox: (0.0185 x 0.0190 x 0.0190) m
[14:10:05]   [LEAF] d=5 F6
[14:10:05]     path: wheel_1_link:1+Wheel_Hub:2+OmniWheelwithHub:1+Omni Wheel:1+A1_ASM:2+F6:3
[14:10:05]     global_pos: (0.233210, -0.134644, -0.028962) m
[14:10:05]     mass: 0.000177 kg, bodies: 2
[14:10:05]     com_global: (0.233210, -0.093144, -0.036962) m
[14:10:05]     com_component_local: (0.000000, 0.041500, -0.008000) m
[14:10:05]     inertia@origin: ixx=3.169158e-07 iyy=2.075227e-08 izz=3.147727e-07 kg·m²
[14:10:05]     inertia@com:    ixx=1.976377e-10 iyy=9.403421e-09 izz=9.403421e-09 kg·m²
[14:10:05]     material: Generic
[14:10:05]     color: RGB(0.31, 0.31, 0.31) [Default]
[14:10:05]     bbox: (0.0320 x 0.0035 x 0.0030) m
[14:10:05]   [LEAF] d=5 F5
[14:10:05]     path: wheel_1_link:1+Wheel_Hub:2+OmniWheelwithHub:1+Omni Wheel:1+A1_ASM:2+F5:4
[14:10:05]     global_pos: (0.233210, -0.134644, -0.028962) m
[14:10:05]     mass: 0.004761 kg, bodies: 1
[14:10:05]     com_global: (0.233210, -0.093144, -0.036962) m
[14:10:05]     com_component_local: (-0.000000, 0.041500, -0.008000) m
[14:10:05]     inertia@origin: ixx=8.717993e-06 iyy=5.403131e-07 izz=8.434997e-06 kg·m²
[14:10:05]     inertia@com:    ixx=2.138575e-07 iyy=2.355876e-07 izz=2.355876e-07 kg·m²
[14:10:05]     material: Generic
[14:10:05]     color: RGB(0.75, 0.75, 0.75) [Opaque_191_191_191]
[14:10:05]     bbox: (0.0185 x 0.0190 x 0.0190) m
[14:10:05]   [LEAF] d=5 F6
[14:10:05]     path: wheel_1_link:1+Wheel_Hub:2+OmniWheelwithHub:1+Omni Wheel:1+A1_ASM:2+F6:4
[14:10:05]     global_pos: (0.233210, -0.134644, -0.028962) m
[14:10:05]     mass: 0.000177 kg, bodies: 2
[14:10:05]     com_global: (0.233210, -0.093144, -0.036962) m
[14:10:05]     com_component_local: (0.000000, 0.041500, -0.008000) m
[14:10:05]     inertia@origin: ixx=3.169158e-07 iyy=2.075227e-08 izz=3.147727e-07 kg·m²
[14:10:05]     inertia@com:    ixx=1.976377e-10 iyy=9.403421e-09 izz=9.403421e-09 kg·m²
[14:10:05]     material: Generic
[14:10:05]     color: RGB(0.31, 0.31, 0.31) [Default]
[14:10:05]     bbox: (0.0320 x 0.0035 x 0.0030) m
[14:10:05]   [LEAF] d=5 F5
[14:10:05]     path: wheel_1_link:1+Wheel_Hub:2+OmniWheelwithHub:1+Omni Wheel:1+A1_ASM:2+F5:5
[14:10:05]     global_pos: (0.233210, -0.134644, -0.028962) m
[14:10:05]     mass: 0.004761 kg, bodies: 1
[14:10:05]     com_global: (0.233210, -0.093144, -0.036962) m
[14:10:05]     com_component_local: (-0.000000, 0.041500, -0.008000) m
[14:10:05]     inertia@origin: ixx=8.717993e-06 iyy=5.403131e-07 izz=8.434997e-06 kg·m²
[14:10:05]     inertia@com:    ixx=2.138575e-07 iyy=2.355876e-07 izz=2.355876e-07 kg·m²
[14:10:05]     material: Generic
[14:10:05]     color: RGB(0.75, 0.75, 0.75) [Opaque_191_191_191]
[14:10:05]     bbox: (0.0185 x 0.0190 x 0.0190) m
[14:10:05]   [LEAF] d=5 F6
[14:10:05]     path: wheel_1_link:1+Wheel_Hub:2+OmniWheelwithHub:1+Omni Wheel:1+A1_ASM:2+F6:5
[14:10:05]     global_pos: (0.233210, -0.134644, -0.028962) m
[14:10:05]     mass: 0.000177 kg, bodies: 2
[14:10:05]     com_global: (0.233210, -0.093144, -0.036962) m
[14:10:05]     com_component_local: (0.000000, 0.041500, -0.008000) m
[14:10:05]     inertia@origin: ixx=3.169158e-07 iyy=2.075227e-08 izz=3.147727e-07 kg·m²
[14:10:05]     inertia@com:    ixx=1.976377e-10 iyy=9.403421e-09 izz=9.403421e-09 kg·m²
[14:10:05]     material: Generic
[14:10:05]     color: RGB(0.31, 0.31, 0.31) [Default]
[14:10:05]     bbox: (0.0320 x 0.0035 x 0.0030) m
[14:10:05]   [LEAF] d=5 F5
[14:10:05]     path: wheel_1_link:1+Wheel_Hub:2+OmniWheelwithHub:1+Omni Wheel:1+A1_ASM:2+F5:6
[14:10:05]     global_pos: (0.233210, -0.134644, -0.028962) m
[14:10:05]     mass: 0.004761 kg, bodies: 1
[14:10:05]     com_global: (0.233210, -0.093144, -0.036962) m
[14:10:05]     com_component_local: (-0.000000, 0.041500, -0.008000) m
[14:10:05]     inertia@origin: ixx=8.717993e-06 iyy=5.403131e-07 izz=8.434997e-06 kg·m²
[14:10:05]     inertia@com:    ixx=2.138575e-07 iyy=2.355876e-07 izz=2.355876e-07 kg·m²
[14:10:05]     material: Generic
[14:10:05]     color: RGB(0.75, 0.75, 0.75) [Opaque_191_191_191]
[14:10:05]     bbox: (0.0185 x 0.0190 x 0.0190) m
[14:10:05]   [LEAF] d=5 F6
[14:10:05]     path: wheel_1_link:1+Wheel_Hub:2+OmniWheelwithHub:1+Omni Wheel:1+A1_ASM:2+F6:6
[14:10:05]     global_pos: (0.233210, -0.134644, -0.028962) m
[14:10:05]     mass: 0.000177 kg, bodies: 2
[14:10:05]     com_global: (0.233210, -0.093144, -0.036962) m
[14:10:05]     com_component_local: (0.000000, 0.041500, -0.008000) m
[14:10:05]     inertia@origin: ixx=3.169158e-07 iyy=2.075227e-08 izz=3.147727e-07 kg·m²
[14:10:05]     inertia@com:    ixx=1.976377e-10 iyy=9.403421e-09 izz=9.403421e-09 kg·m²
[14:10:05]     material: Generic
[14:10:05]     color: RGB(0.31, 0.31, 0.31) [Default]
[14:10:05]     bbox: (0.0320 x 0.0035 x 0.0030) m
[14:10:05]   [LEAF] d=5 F5
[14:10:05]     path: wheel_1_link:1+Wheel_Hub:2+OmniWheelwithHub:1+Omni Wheel:1+A1_ASM:2+F5:7
[14:10:05]     global_pos: (0.233210, -0.134644, -0.028962) m
[14:10:05]     mass: 0.004761 kg, bodies: 1
[14:10:05]     com_global: (0.233210, -0.093144, -0.036962) m
[14:10:05]     com_component_local: (-0.000000, 0.041500, -0.008000) m
[14:10:05]     inertia@origin: ixx=8.717993e-06 iyy=5.403131e-07 izz=8.434997e-06 kg·m²
[14:10:05]     inertia@com:    ixx=2.138575e-07 iyy=2.355876e-07 izz=2.355876e-07 kg·m²
[14:10:05]     material: Generic
[14:10:05]     color: RGB(0.75, 0.75, 0.75) [Opaque_191_191_191]
[14:10:05]     bbox: (0.0185 x 0.0190 x 0.0190) m
[14:10:05]   [LEAF] d=5 F6
[14:10:05]     path: wheel_1_link:1+Wheel_Hub:2+OmniWheelwithHub:1+Omni Wheel:1+A1_ASM:2+F6:7
[14:10:05]     global_pos: (0.233210, -0.134644, -0.028962) m
[14:10:05]     mass: 0.000177 kg, bodies: 2
[14:10:05]     com_global: (0.233210, -0.093144, -0.036962) m
[14:10:05]     com_component_local: (0.000000, 0.041500, -0.008000) m
[14:10:05]     inertia@origin: ixx=3.169158e-07 iyy=2.075227e-08 izz=3.147727e-07 kg·m²
[14:10:05]     inertia@com:    ixx=1.976377e-10 iyy=9.403421e-09 izz=9.403421e-09 kg·m²
[14:10:05]     material: Generic
[14:10:05]     color: RGB(0.31, 0.31, 0.31) [Default]
[14:10:05]     bbox: (0.0320 x 0.0035 x 0.0030) m
[14:10:05]   [LEAF] d=5 F5
[14:10:05]     path: wheel_1_link:1+Wheel_Hub:2+OmniWheelwithHub:1+Omni Wheel:1+A1_ASM:2+F5:8
[14:10:05]     global_pos: (0.233210, -0.134644, -0.028962) m
[14:10:05]     mass: 0.004761 kg, bodies: 1
[14:10:05]     com_global: (0.233210, -0.093144, -0.036962) m
[14:10:05]     com_component_local: (-0.000000, 0.041500, -0.008000) m
[14:10:05]     inertia@origin: ixx=8.717993e-06 iyy=5.403131e-07 izz=8.434997e-06 kg·m²
[14:10:05]     inertia@com:    ixx=2.138575e-07 iyy=2.355876e-07 izz=2.355876e-07 kg·m²
[14:10:05]     material: Generic
[14:10:05]     color: RGB(0.75, 0.75, 0.75) [Opaque_191_191_191]
[14:10:05]     bbox: (0.0185 x 0.0190 x 0.0190) m
[14:10:05]   [LEAF] d=5 F6
[14:10:05]     path: wheel_1_link:1+Wheel_Hub:2+OmniWheelwithHub:1+Omni Wheel:1+A1_ASM:2+F6:8
[14:10:05]     global_pos: (0.233210, -0.134644, -0.028962) m
[14:10:05]     mass: 0.000177 kg, bodies: 2
[14:10:05]     com_global: (0.233210, -0.093144, -0.036962) m
[14:10:05]     com_component_local: (0.000000, 0.041500, -0.008000) m
[14:10:05]     inertia@origin: ixx=3.169158e-07 iyy=2.075227e-08 izz=3.147727e-07 kg·m²
[14:10:05]     inertia@com:    ixx=1.976377e-10 iyy=9.403421e-09 izz=9.403421e-09 kg·m²
[14:10:05]     material: Generic
[14:10:05]     color: RGB(0.31, 0.31, 0.31) [Default]
[14:10:05]     bbox: (0.0320 x 0.0035 x 0.0030) m
[14:10:05]   [LEAF] d=5 F5
[14:10:05]     path: wheel_1_link:1+Wheel_Hub:2+OmniWheelwithHub:1+Omni Wheel:1+A1_ASM:2+F5:9
[14:10:05]     global_pos: (0.233210, -0.134644, -0.028962) m
[14:10:05]     mass: 0.004761 kg, bodies: 1
[14:10:05]     com_global: (0.233210, -0.093144, -0.036962) m
[14:10:05]     com_component_local: (-0.000000, 0.041500, -0.008000) m
[14:10:05]     inertia@origin: ixx=8.717993e-06 iyy=5.403131e-07 izz=8.434997e-06 kg·m²
[14:10:05]     inertia@com:    ixx=2.138575e-07 iyy=2.355876e-07 izz=2.355876e-07 kg·m²
[14:10:05]     material: Generic
[14:10:05]     color: RGB(0.75, 0.75, 0.75) [Opaque_191_191_191]
[14:10:05]     bbox: (0.0185 x 0.0190 x 0.0190) m
[14:10:05]   [LEAF] d=5 F6
[14:10:05]     path: wheel_1_link:1+Wheel_Hub:2+OmniWheelwithHub:1+Omni Wheel:1+A1_ASM:2+F6:9
[14:10:05]     global_pos: (0.233210, -0.134644, -0.028962) m
[14:10:05]     mass: 0.000177 kg, bodies: 2
[14:10:05]     com_global: (0.233210, -0.093144, -0.036962) m
[14:10:05]     com_component_local: (0.000000, 0.041500, -0.008000) m
[14:10:05]     inertia@origin: ixx=3.169158e-07 iyy=2.075227e-08 izz=3.147727e-07 kg·m²
[14:10:05]     inertia@com:    ixx=1.976377e-10 iyy=9.403421e-09 izz=9.403421e-09 kg·m²
[14:10:05]     material: Generic
[14:10:05]     color: RGB(0.31, 0.31, 0.31) [Default]
[14:10:05]     bbox: (0.0320 x 0.0035 x 0.0030) m
[14:10:05]   [LEAF] d=5 F2
[14:10:05]     path: wheel_1_link:1+Wheel_Hub:2+OmniWheelwithHub:1+Omni Wheel:1+A1_ASM:2+F2:2
[14:10:05]     global_pos: (0.247067, -0.142644, -0.028962) m
[14:10:05]     mass: 0.021208 kg, bodies: 1
[14:10:05]     com_global: (0.247097, -0.142644, -0.040323) m
[14:10:05]     com_component_local: (0.000030, 0.000000, -0.011361) m
[14:10:05]     inertia@origin: ixx=1.263883e-05 iyy=1.263752e-05 izz=1.962197e-05 kg·m²
[14:10:05]     inertia@com:    ixx=9.901373e-06 iyy=9.900039e-06 izz=1.962195e-05 kg·m²
[14:10:05]     material: Generic
[14:10:05]     color: RGB(0.75, 0.75, 0.75) [Opaque_191_191_191]
[14:10:05]     bbox: (0.0945 x 0.0933 x 0.0100) m
[14:10:05]   [SUBASM] d=4 A1_ASM
[14:10:05]     path: wheel_1_link:1+Wheel_Hub:2+OmniWheelwithHub:1+Omni Wheel:1+A1_ASM:2
[14:10:05]     global_pos: (0.233210, -0.134644, -0.028962) m
[14:10:05]   [SUBASM] d=3 Omni_Wheel
[14:10:05]     path: wheel_1_link:1+Wheel_Hub:2+OmniWheelwithHub:1+Omni Wheel:1
[14:10:05]     global_pos: (0.264734, -0.152844, -0.028962) m
[14:10:05]   [LEAF] d=3 6mm_Mount
[14:10:05]     path: wheel_1_link:1+Wheel_Hub:2+OmniWheelwithHub:1+6mm_Mount:1
[14:10:05]     global_pos: (0.246981, -0.142594, -0.028962) m
[14:10:05]     mass: 0.006982 kg, bodies: 1
[14:10:05]     com_global: (0.247027, -0.129307, -0.029008) m
[14:10:05]     com_component_local: (0.000046, 0.013287, -0.000046) m
[14:10:05]     inertia@origin: ixx=1.824828e-06 iyy=3.446660e-07 izz=1.824829e-06 kg·m²
[14:10:05]     inertia@com:    ixx=5.920723e-07 iyy=3.446366e-07 izz=5.920737e-07 kg·m²
[14:10:05]     material: Generic
[14:10:05]     color: RGB(0.75, 0.75, 0.75) [Opaque_191_191_191]
[14:10:05]     bbox: (0.0218 x 0.0295 x 0.0218) m
[14:10:05]   [LEAF] d=3 Back_Spacer
[14:10:05]     path: wheel_1_link:1+Wheel_Hub:2+OmniWheelwithHub:1+Back Spacer:1
[14:10:05]     global_pos: (0.246201, -0.142144, -0.028962) m
[14:10:05]     mass: 0.002393 kg, bodies: 1
[14:10:05]     com_global: (0.246201, -0.138644, -0.028962) m
[14:10:05]     com_component_local: (-0.000000, 0.003500, 0.000000) m
[14:10:05]     inertia@origin: ixx=1.150960e-07 iyy=1.523277e-07 izz=1.150960e-07 kg·m²
[14:10:05]     inertia@com:    ixx=8.578160e-08 iyy=1.523277e-07 izz=8.578158e-08 kg·m²
[14:10:05]     material: Generic
[14:10:05]     color: RGB(0.75, 0.75, 0.75) [Opaque_191_191_191]
[14:10:05]     bbox: (0.0218 x 0.0070 x 0.0218) m
[14:10:05]   [SUBASM] d=2 OmniWheelwithHub
[14:10:05]     path: wheel_1_link:1+Wheel_Hub:2+OmniWheelwithHub:1
[14:10:05]     global_pos: (0.200532, -0.107980, -0.019756) m
[14:10:05]   [LEAF] d=2 Motor_Hub
[14:10:05]     path: wheel_1_link:1+Wheel_Hub:2+Motor_Hub:1
[14:10:05]     global_pos: (0.234076, -0.135144, -0.028962) m
[14:10:05]     mass: 0.118971 kg, bodies: 1
[14:10:05]     com_global: (0.234076, -0.135144, -0.025341) m
[14:10:05]     com_component_local: (0.000000, 0.000000, 0.003621) m
[14:10:05]     inertia@origin: ixx=2.302890e-05 iyy=2.302891e-05 izz=4.124951e-05 kg·m²
[14:10:05]     inertia@com:    ixx=2.146927e-05 iyy=2.146928e-05 izz=4.124951e-05 kg·m²
[14:10:05]     material: Steel
[14:10:05]     color: RGB(0.07, 0.13, 0.50) [ABS_White_1]
[14:10:05]     bbox: (0.0576 x 0.0576 x 0.0110) m
[14:10:05]   [SUBASM] d=1 Wheel_Hub
[14:10:05]     path: wheel_1_link:1+Wheel_Hub:2
[14:10:05]     global_pos: (0.234076, -0.135144, -0.028962) m
[14:10:05]   [LEAF] d=1 4mm_Rigid_Flange_Coupling
[14:10:05]     path: wheel_1_link:1+4mm_Rigid_Flange_Coupling:2
[14:10:05]     global_pos: (0.234076, -0.135144, -0.028962) m
[14:10:05]     mass: 0.003505 kg, bodies: 1
[14:10:05]     com_global: (0.234031, -0.131286, -0.029007) m
[14:10:05]     com_component_local: (-0.000045, 0.003858, -0.000045) m
[14:10:05]     inertia@origin: ixx=1.676406e-07 iyy=1.384679e-07 izz=1.676407e-07 kg·m²
[14:10:05]     inertia@com:    ixx=1.154665e-07 iyy=1.384538e-07 izz=1.154665e-07 kg·m²
[14:10:05]     material: Aluminum
[14:10:05]     color: RGB(0.96, 0.96, 0.96) [Aluminum_Satin]
[14:10:05]     bbox: (0.0220 x 0.0120 x 0.0220) m
[14:10:05]   [LEAF] d=1 Omni_Wheel
[14:10:05]     path: wheel_1_link:1+Omni_Wheel:1
[14:10:05]     global_pos: (-0.094909, -0.073309, -0.634871) m
[14:10:05]     mass: 1.479811 kg, bodies: 60
[14:10:05]     com_global: (-0.112228, -0.189640, 0.058153) m
[14:10:05]     com_component_local: (-0.017319, -0.116331, 0.693024) m
[14:10:05]     inertia@origin: ixx=7.324645e-01 iyy=7.122855e-01 izz=2.176439e-02 kg·m²
[14:10:05]     inertia@com:    ixx=1.711535e-03 iyy=1.114997e-03 izz=1.294264e-03 kg·m²
[14:10:05]     material: Steel
[14:10:05]     color: RGB(0.37, 0.42, 0.51) [PA_12_Nylon_PA_603_CF_with_EOS_P_3D_Printers]
[14:10:05]     bbox: (0.0766 x 0.1022 x 0.1017) m
[14:10:05]   [SUBASM] d=0 wheel_1_link
[14:10:05]     path: wheel_1_link:1
[14:10:05]     global_pos: (0.000000, 0.000000, 0.000000) m
[14:10:05]   [LEAF] d=1 Omni_Wheel
[14:10:05]     path: wheel_2_link:1+Omni_Wheel:3
[14:10:05]     global_pos: (0.132999, -0.053696, -0.625992) m
[14:10:05]     mass: 1.479811 kg, bodies: 60
[14:10:05]     com_global: (0.115680, -0.170027, 0.067032) m
[14:10:05]     com_component_local: (-0.017319, -0.116331, 0.693024) m
[14:10:05]     inertia@origin: ixx=7.324645e-01 iyy=7.122855e-01 izz=2.176439e-02 kg·m²
[14:10:05]     inertia@com:    ixx=1.711535e-03 iyy=1.114997e-03 izz=1.294264e-03 kg·m²
[14:10:05]     material: Steel
[14:10:05]     color: RGB(0.37, 0.42, 0.51) [PA_12_Nylon_PA_603_CF_with_EOS_P_3D_Printers]
[14:10:05]     bbox: (0.0766 x 0.1022 x 0.1017) m
[14:10:05]   [LEAF] d=1 4mm_Rigid_Flange_Coupling
[14:10:05]     path: wheel_2_link:1+4mm_Rigid_Flange_Coupling:3
[14:10:05]     global_pos: (-0.000000, 0.270287, -0.028962) m
[14:10:05]     mass: 0.003505 kg, bodies: 1
[14:10:05]     com_global: (-0.000045, 0.274145, -0.029007) m
[14:10:05]     com_component_local: (-0.000045, 0.003858, -0.000045) m
[14:10:05]     inertia@origin: ixx=1.676406e-07 iyy=1.384679e-07 izz=1.676407e-07 kg·m²
[14:10:05]     inertia@com:    ixx=1.154665e-07 iyy=1.384538e-07 izz=1.154665e-07 kg·m²
[14:10:05]     material: Aluminum
[14:10:05]     color: RGB(0.96, 0.96, 0.96) [Aluminum_Satin]
[14:10:05]     bbox: (0.0220 x 0.0120 x 0.0220) m
[14:10:05]   [LEAF] d=5 F2
[14:10:05]     path: wheel_2_link:1+Wheel_Hub:3+OmniWheelwithHub:1+Omni Wheel:1+A1_ASM:1+F2:1
[14:10:05]     global_pos: (-0.000000, 0.305689, -0.028962) m
[14:10:05]     mass: 0.021208 kg, bodies: 1
[14:10:05]     com_global: (0.000030, 0.305689, -0.040323) m
[14:10:05]     com_component_local: (0.000030, 0.000000, -0.011361) m
[14:10:05]     inertia@origin: ixx=1.263883e-05 iyy=1.263752e-05 izz=1.962197e-05 kg·m²
[14:10:05]     inertia@com:    ixx=9.901373e-06 iyy=9.900039e-06 izz=1.962195e-05 kg·m²
[14:10:05]     material: Generic
[14:10:05]     color: RGB(0.75, 0.75, 0.75) [Opaque_191_191_191]
[14:10:05]     bbox: (0.0945 x 0.0933 x 0.0100) m
[14:10:05]   [LEAF] d=5 F5
[14:10:05]     path: wheel_2_link:1+Wheel_Hub:3+OmniWheelwithHub:1+Omni Wheel:1+A1_ASM:1+F5:1
[14:10:05]     global_pos: (-0.000000, 0.305689, -0.028962) m
[14:10:05]     mass: 0.004761 kg, bodies: 1
[14:10:05]     com_global: (-0.000000, 0.347189, -0.036962) m
[14:10:05]     com_component_local: (-0.000000, 0.041500, -0.008000) m
[14:10:05]     inertia@origin: ixx=8.717993e-06 iyy=5.403131e-07 izz=8.434997e-06 kg·m²
[14:10:05]     inertia@com:    ixx=2.138575e-07 iyy=2.355876e-07 izz=2.355876e-07 kg·m²
[14:10:05]     material: Generic
[14:10:05]     color: RGB(0.75, 0.75, 0.75) [Opaque_191_191_191]
[14:10:05]     bbox: (0.0185 x 0.0190 x 0.0190) m
[14:10:05]   [LEAF] d=5 F6
[14:10:05]     path: wheel_2_link:1+Wheel_Hub:3+OmniWheelwithHub:1+Omni Wheel:1+A1_ASM:1+F6:1
[14:10:05]     global_pos: (-0.000000, 0.305689, -0.028962) m
[14:10:05]     mass: 0.000177 kg, bodies: 2
[14:10:05]     com_global: (-0.000000, 0.347189, -0.036962) m
[14:10:05]     com_component_local: (0.000000, 0.041500, -0.008000) m
[14:10:05]     inertia@origin: ixx=3.169158e-07 iyy=2.075227e-08 izz=3.147727e-07 kg·m²
[14:10:05]     inertia@com:    ixx=1.976377e-10 iyy=9.403421e-09 izz=9.403421e-09 kg·m²
[14:10:05]     material: Generic
[14:10:05]     color: RGB(0.31, 0.31, 0.31) [Default]
[14:10:05]     bbox: (0.0320 x 0.0035 x 0.0030) m
[14:10:05]   [LEAF] d=5 F5
[14:10:05]     path: wheel_2_link:1+Wheel_Hub:3+OmniWheelwithHub:1+Omni Wheel:1+A1_ASM:1+F5:2
[14:10:05]     global_pos: (-0.000000, 0.305689, -0.028962) m
[14:10:05]     mass: 0.004761 kg, bodies: 1
[14:10:05]     com_global: (-0.000000, 0.347189, -0.036962) m
[14:10:05]     com_component_local: (-0.000000, 0.041500, -0.008000) m
[14:10:05]     inertia@origin: ixx=8.717993e-06 iyy=5.403131e-07 izz=8.434997e-06 kg·m²
[14:10:05]     inertia@com:    ixx=2.138575e-07 iyy=2.355876e-07 izz=2.355876e-07 kg·m²
[14:10:05]     material: Generic
[14:10:05]     color: RGB(0.75, 0.75, 0.75) [Opaque_191_191_191]
[14:10:05]     bbox: (0.0185 x 0.0190 x 0.0190) m
[14:10:05]   [LEAF] d=5 F6
[14:10:05]     path: wheel_2_link:1+Wheel_Hub:3+OmniWheelwithHub:1+Omni Wheel:1+A1_ASM:1+F6:2
[14:10:05]     global_pos: (-0.000000, 0.305689, -0.028962) m
[14:10:05]     mass: 0.000177 kg, bodies: 2
[14:10:05]     com_global: (-0.000000, 0.347189, -0.036962) m
[14:10:05]     com_component_local: (0.000000, 0.041500, -0.008000) m
[14:10:05]     inertia@origin: ixx=3.169158e-07 iyy=2.075227e-08 izz=3.147727e-07 kg·m²
[14:10:05]     inertia@com:    ixx=1.976377e-10 iyy=9.403421e-09 izz=9.403421e-09 kg·m²
[14:10:05]     material: Generic
[14:10:05]     color: RGB(0.31, 0.31, 0.31) [Default]
[14:10:05]     bbox: (0.0320 x 0.0035 x 0.0030) m
[14:10:05]   [LEAF] d=5 F5
[14:10:05]     path: wheel_2_link:1+Wheel_Hub:3+OmniWheelwithHub:1+Omni Wheel:1+A1_ASM:1+F5:3
[14:10:05]     global_pos: (-0.000000, 0.305689, -0.028962) m
[14:10:05]     mass: 0.004761 kg, bodies: 1
[14:10:05]     com_global: (-0.000000, 0.347189, -0.036962) m
[14:10:05]     com_component_local: (-0.000000, 0.041500, -0.008000) m
[14:10:05]     inertia@origin: ixx=8.717993e-06 iyy=5.403131e-07 izz=8.434997e-06 kg·m²
[14:10:05]     inertia@com:    ixx=2.138575e-07 iyy=2.355876e-07 izz=2.355876e-07 kg·m²
[14:10:05]     material: Generic
[14:10:05]     color: RGB(0.75, 0.75, 0.75) [Opaque_191_191_191]
[14:10:05]     bbox: (0.0185 x 0.0190 x 0.0190) m
[14:10:05]   [LEAF] d=5 F6
[14:10:05]     path: wheel_2_link:1+Wheel_Hub:3+OmniWheelwithHub:1+Omni Wheel:1+A1_ASM:1+F6:3
[14:10:05]     global_pos: (-0.000000, 0.305689, -0.028962) m
[14:10:05]     mass: 0.000177 kg, bodies: 2
[14:10:05]     com_global: (-0.000000, 0.347189, -0.036962) m
[14:10:05]     com_component_local: (0.000000, 0.041500, -0.008000) m
[14:10:05]     inertia@origin: ixx=3.169158e-07 iyy=2.075227e-08 izz=3.147727e-07 kg·m²
[14:10:05]     inertia@com:    ixx=1.976377e-10 iyy=9.403421e-09 izz=9.403421e-09 kg·m²
[14:10:05]     material: Generic
[14:10:05]     color: RGB(0.31, 0.31, 0.31) [Default]
[14:10:05]     bbox: (0.0320 x 0.0035 x 0.0030) m
[14:10:05]   [LEAF] d=5 F5
[14:10:05]     path: wheel_2_link:1+Wheel_Hub:3+OmniWheelwithHub:1+Omni Wheel:1+A1_ASM:1+F5:4
[14:10:05]     global_pos: (-0.000000, 0.305689, -0.028962) m
[14:10:05]     mass: 0.004761 kg, bodies: 1
[14:10:05]     com_global: (-0.000000, 0.347189, -0.036962) m
[14:10:05]     com_component_local: (-0.000000, 0.041500, -0.008000) m
[14:10:05]     inertia@origin: ixx=8.717993e-06 iyy=5.403131e-07 izz=8.434997e-06 kg·m²
[14:10:05]     inertia@com:    ixx=2.138575e-07 iyy=2.355876e-07 izz=2.355876e-07 kg·m²
[14:10:05]     material: Generic
[14:10:05]     color: RGB(0.75, 0.75, 0.75) [Opaque_191_191_191]
[14:10:05]     bbox: (0.0185 x 0.0190 x 0.0190) m
[14:10:05]   [LEAF] d=5 F6
[14:10:05]     path: wheel_2_link:1+Wheel_Hub:3+OmniWheelwithHub:1+Omni Wheel:1+A1_ASM:1+F6:4
[14:10:05]     global_pos: (-0.000000, 0.305689, -0.028962) m
[14:10:05]     mass: 0.000177 kg, bodies: 2
[14:10:05]     com_global: (-0.000000, 0.347189, -0.036962) m
[14:10:05]     com_component_local: (0.000000, 0.041500, -0.008000) m
[14:10:05]     inertia@origin: ixx=3.169158e-07 iyy=2.075227e-08 izz=3.147727e-07 kg·m²
[14:10:05]     inertia@com:    ixx=1.976377e-10 iyy=9.403421e-09 izz=9.403421e-09 kg·m²
[14:10:05]     material: Generic
[14:10:05]     color: RGB(0.31, 0.31, 0.31) [Default]
[14:10:05]     bbox: (0.0320 x 0.0035 x 0.0030) m
[14:10:05]   [LEAF] d=5 F5
[14:10:05]     path: wheel_2_link:1+Wheel_Hub:3+OmniWheelwithHub:1+Omni Wheel:1+A1_ASM:1+F5:5
[14:10:05]     global_pos: (-0.000000, 0.305689, -0.028962) m
[14:10:05]     mass: 0.004761 kg, bodies: 1
[14:10:05]     com_global: (-0.000000, 0.347189, -0.036962) m
[14:10:05]     com_component_local: (-0.000000, 0.041500, -0.008000) m
[14:10:05]     inertia@origin: ixx=8.717993e-06 iyy=5.403131e-07 izz=8.434997e-06 kg·m²
[14:10:05]     inertia@com:    ixx=2.138575e-07 iyy=2.355876e-07 izz=2.355876e-07 kg·m²
[14:10:05]     material: Generic
[14:10:05]     color: RGB(0.75, 0.75, 0.75) [Opaque_191_191_191]
[14:10:05]     bbox: (0.0185 x 0.0190 x 0.0190) m
[14:10:05]   [LEAF] d=5 F6
[14:10:05]     path: wheel_2_link:1+Wheel_Hub:3+OmniWheelwithHub:1+Omni Wheel:1+A1_ASM:1+F6:5
[14:10:05]     global_pos: (-0.000000, 0.305689, -0.028962) m
[14:10:05]     mass: 0.000177 kg, bodies: 2
[14:10:05]     com_global: (-0.000000, 0.347189, -0.036962) m
[14:10:05]     com_component_local: (0.000000, 0.041500, -0.008000) m
[14:10:05]     inertia@origin: ixx=3.169158e-07 iyy=2.075227e-08 izz=3.147727e-07 kg·m²
[14:10:05]     inertia@com:    ixx=1.976377e-10 iyy=9.403421e-09 izz=9.403421e-09 kg·m²
[14:10:05]     material: Generic
[14:10:05]     color: RGB(0.31, 0.31, 0.31) [Default]
[14:10:05]     bbox: (0.0320 x 0.0035 x 0.0030) m
[14:10:05]   [LEAF] d=5 F5
[14:10:05]     path: wheel_2_link:1+Wheel_Hub:3+OmniWheelwithHub:1+Omni Wheel:1+A1_ASM:1+F5:6
[14:10:05]     global_pos: (-0.000000, 0.305689, -0.028962) m
[14:10:05]     mass: 0.004761 kg, bodies: 1
[14:10:05]     com_global: (-0.000000, 0.347189, -0.036962) m
[14:10:05]     com_component_local: (-0.000000, 0.041500, -0.008000) m
[14:10:05]     inertia@origin: ixx=8.717993e-06 iyy=5.403131e-07 izz=8.434997e-06 kg·m²
[14:10:05]     inertia@com:    ixx=2.138575e-07 iyy=2.355876e-07 izz=2.355876e-07 kg·m²
[14:10:05]     material: Generic
[14:10:05]     color: RGB(0.75, 0.75, 0.75) [Opaque_191_191_191]
[14:10:05]     bbox: (0.0185 x 0.0190 x 0.0190) m
[14:10:05]   [LEAF] d=5 F6
[14:10:05]     path: wheel_2_link:1+Wheel_Hub:3+OmniWheelwithHub:1+Omni Wheel:1+A1_ASM:1+F6:6
[14:10:05]     global_pos: (-0.000000, 0.305689, -0.028962) m
[14:10:05]     mass: 0.000177 kg, bodies: 2
[14:10:05]     com_global: (-0.000000, 0.347189, -0.036962) m
[14:10:05]     com_component_local: (0.000000, 0.041500, -0.008000) m
[14:10:05]     inertia@origin: ixx=3.169158e-07 iyy=2.075227e-08 izz=3.147727e-07 kg·m²
[14:10:05]     inertia@com:    ixx=1.976377e-10 iyy=9.403421e-09 izz=9.403421e-09 kg·m²
[14:10:05]     material: Generic
[14:10:05]     color: RGB(0.31, 0.31, 0.31) [Default]
[14:10:05]     bbox: (0.0320 x 0.0035 x 0.0030) m
[14:10:05]   [LEAF] d=5 F5
[14:10:05]     path: wheel_2_link:1+Wheel_Hub:3+OmniWheelwithHub:1+Omni Wheel:1+A1_ASM:1+F5:7
[14:10:05]     global_pos: (-0.000000, 0.305689, -0.028962) m
[14:10:05]     mass: 0.004761 kg, bodies: 1
[14:10:05]     com_global: (-0.000000, 0.347189, -0.036962) m
[14:10:05]     com_component_local: (-0.000000, 0.041500, -0.008000) m
[14:10:05]     inertia@origin: ixx=8.717993e-06 iyy=5.403131e-07 izz=8.434997e-06 kg·m²
[14:10:05]     inertia@com:    ixx=2.138575e-07 iyy=2.355876e-07 izz=2.355876e-07 kg·m²
[14:10:05]     material: Generic
[14:10:05]     color: RGB(0.75, 0.75, 0.75) [Opaque_191_191_191]
[14:10:05]     bbox: (0.0185 x 0.0190 x 0.0190) m
[14:10:05]   [LEAF] d=5 F6
[14:10:05]     path: wheel_2_link:1+Wheel_Hub:3+OmniWheelwithHub:1+Omni Wheel:1+A1_ASM:1+F6:7
[14:10:05]     global_pos: (-0.000000, 0.305689, -0.028962) m
[14:10:05]     mass: 0.000177 kg, bodies: 2
[14:10:05]     com_global: (-0.000000, 0.347189, -0.036962) m
[14:10:05]     com_component_local: (0.000000, 0.041500, -0.008000) m
[14:10:05]     inertia@origin: ixx=3.169158e-07 iyy=2.075227e-08 izz=3.147727e-07 kg·m²
[14:10:05]     inertia@com:    ixx=1.976377e-10 iyy=9.403421e-09 izz=9.403421e-09 kg·m²
[14:10:05]     material: Generic
[14:10:05]     color: RGB(0.31, 0.31, 0.31) [Default]
[14:10:05]     bbox: (0.0320 x 0.0035 x 0.0030) m
[14:10:05]   [LEAF] d=5 F5
[14:10:05]     path: wheel_2_link:1+Wheel_Hub:3+OmniWheelwithHub:1+Omni Wheel:1+A1_ASM:1+F5:8
[14:10:05]     global_pos: (-0.000000, 0.305689, -0.028962) m
[14:10:05]     mass: 0.004761 kg, bodies: 1
[14:10:05]     com_global: (-0.000000, 0.347189, -0.036962) m
[14:10:05]     com_component_local: (-0.000000, 0.041500, -0.008000) m
[14:10:05]     inertia@origin: ixx=8.717993e-06 iyy=5.403131e-07 izz=8.434997e-06 kg·m²
[14:10:05]     inertia@com:    ixx=2.138575e-07 iyy=2.355876e-07 izz=2.355876e-07 kg·m²
[14:10:05]     material: Generic
[14:10:05]     color: RGB(0.75, 0.75, 0.75) [Opaque_191_191_191]
[14:10:05]     bbox: (0.0185 x 0.0190 x 0.0190) m
[14:10:05]   [LEAF] d=5 F6
[14:10:05]     path: wheel_2_link:1+Wheel_Hub:3+OmniWheelwithHub:1+Omni Wheel:1+A1_ASM:1+F6:8
[14:10:05]     global_pos: (-0.000000, 0.305689, -0.028962) m
[14:10:05]     mass: 0.000177 kg, bodies: 2
[14:10:05]     com_global: (-0.000000, 0.347189, -0.036962) m
[14:10:05]     com_component_local: (0.000000, 0.041500, -0.008000) m
[14:10:05]     inertia@origin: ixx=3.169158e-07 iyy=2.075227e-08 izz=3.147727e-07 kg·m²
[14:10:05]     inertia@com:    ixx=1.976377e-10 iyy=9.403421e-09 izz=9.403421e-09 kg·m²
[14:10:05]     material: Generic
[14:10:05]     color: RGB(0.31, 0.31, 0.31) [Default]
[14:10:05]     bbox: (0.0320 x 0.0035 x 0.0030) m
[14:10:05]   [LEAF] d=5 F5
[14:10:05]     path: wheel_2_link:1+Wheel_Hub:3+OmniWheelwithHub:1+Omni Wheel:1+A1_ASM:1+F5:9
[14:10:05]     global_pos: (-0.000000, 0.305689, -0.028962) m
[14:10:05]     mass: 0.004761 kg, bodies: 1
[14:10:05]     com_global: (-0.000000, 0.347189, -0.036962) m
[14:10:05]     com_component_local: (-0.000000, 0.041500, -0.008000) m
[14:10:05]     inertia@origin: ixx=8.717993e-06 iyy=5.403131e-07 izz=8.434997e-06 kg·m²
[14:10:05]     inertia@com:    ixx=2.138575e-07 iyy=2.355876e-07 izz=2.355876e-07 kg·m²
[14:10:05]     material: Generic
[14:10:05]     color: RGB(0.75, 0.75, 0.75) [Opaque_191_191_191]
[14:10:05]     bbox: (0.0185 x 0.0190 x 0.0190) m
[14:10:05]   [LEAF] d=5 F6
[14:10:05]     path: wheel_2_link:1+Wheel_Hub:3+OmniWheelwithHub:1+Omni Wheel:1+A1_ASM:1+F6:9
[14:10:05]     global_pos: (-0.000000, 0.305689, -0.028962) m
[14:10:05]     mass: 0.000177 kg, bodies: 2
[14:10:05]     com_global: (-0.000000, 0.347189, -0.036962) m
[14:10:05]     com_component_local: (0.000000, 0.041500, -0.008000) m
[14:10:05]     inertia@origin: ixx=3.169158e-07 iyy=2.075227e-08 izz=3.147727e-07 kg·m²
[14:10:05]     inertia@com:    ixx=1.976377e-10 iyy=9.403421e-09 izz=9.403421e-09 kg·m²
[14:10:05]     material: Generic
[14:10:05]     color: RGB(0.31, 0.31, 0.31) [Default]
[14:10:05]     bbox: (0.0320 x 0.0035 x 0.0030) m
[14:10:06]   [LEAF] d=5 F2
[14:10:06]     path: wheel_2_link:1+Wheel_Hub:3+OmniWheelwithHub:1+Omni Wheel:1+A1_ASM:1+F2:2
[14:10:06]     global_pos: (-0.000000, 0.289688, -0.028962) m
[14:10:06]     mass: 0.021208 kg, bodies: 1
[14:10:06]     com_global: (0.000030, 0.289688, -0.040323) m
[14:10:06]     com_component_local: (0.000030, 0.000000, -0.011361) m
[14:10:06]     inertia@origin: ixx=1.263883e-05 iyy=1.263752e-05 izz=1.962197e-05 kg·m²
[14:10:06]     inertia@com:    ixx=9.901373e-06 iyy=9.900039e-06 izz=1.962195e-05 kg·m²
[14:10:06]     material: Generic
[14:10:06]     color: RGB(0.75, 0.75, 0.75) [Opaque_191_191_191]
[14:10:06]     bbox: (0.0945 x 0.0933 x 0.0100) m
[14:10:06]   [SUBASM] d=4 A1_ASM
[14:10:06]     path: wheel_2_link:1+Wheel_Hub:3+OmniWheelwithHub:1+Omni Wheel:1+A1_ASM:1
[14:10:06]     global_pos: (-0.000000, 0.305689, -0.028962) m
[14:10:06]   [LEAF] d=4 F12
[14:10:06]     path: wheel_2_link:1+Wheel_Hub:3+OmniWheelwithHub:1+Omni Wheel:1+F12:1
[14:10:06]     global_pos: (-0.000000, 0.305689, -0.028962) m
[14:10:06]     mass: 0.012397 kg, bodies: 1
[14:10:06]     com_global: (0.000000, 0.305689, -0.046210) m
[14:10:06]     com_component_local: (0.000000, -0.000000, -0.017248) m
[14:10:06]     inertia@origin: ixx=6.165417e-06 iyy=6.165417e-06 izz=4.749610e-06 kg·m²
[14:10:06]     inertia@com:    ixx=2.477412e-06 iyy=2.477413e-06 izz=4.749610e-06 kg·m²
[14:10:06]     material: Generic
[14:10:06]     color: RGB(0.75, 0.75, 0.75) [Opaque_191_191_191]
[14:10:06]     bbox: (0.0567 x 0.0567 x 0.0134) m
[14:10:06]   [LEAF] d=5 F2
[14:10:06]     path: wheel_2_link:1+Wheel_Hub:3+OmniWheelwithHub:1+Omni Wheel:1+A1_ASM:2+F2:1
[14:10:06]     global_pos: (-0.000000, 0.269287, -0.028962) m
[14:10:06]     mass: 0.021208 kg, bodies: 1
[14:10:06]     com_global: (0.000030, 0.269287, -0.040323) m
[14:10:06]     com_component_local: (0.000030, 0.000000, -0.011361) m
[14:10:06]     inertia@origin: ixx=1.263883e-05 iyy=1.263752e-05 izz=1.962197e-05 kg·m²
[14:10:06]     inertia@com:    ixx=9.901373e-06 iyy=9.900039e-06 izz=1.962195e-05 kg·m²
[14:10:06]     material: Generic
[14:10:06]     color: RGB(0.75, 0.75, 0.75) [Opaque_191_191_191]
[14:10:06]     bbox: (0.0945 x 0.0933 x 0.0100) m
[14:10:06]   [LEAF] d=5 F5
[14:10:06]     path: wheel_2_link:1+Wheel_Hub:3+OmniWheelwithHub:1+Omni Wheel:1+A1_ASM:2+F5:1
[14:10:06]     global_pos: (-0.000000, 0.269287, -0.028962) m
[14:10:06]     mass: 0.004761 kg, bodies: 1
[14:10:06]     com_global: (-0.000000, 0.310787, -0.036962) m
[14:10:06]     com_component_local: (-0.000000, 0.041500, -0.008000) m
[14:10:06]     inertia@origin: ixx=8.717993e-06 iyy=5.403131e-07 izz=8.434997e-06 kg·m²
[14:10:06]     inertia@com:    ixx=2.138575e-07 iyy=2.355876e-07 izz=2.355876e-07 kg·m²
[14:10:06]     material: Generic
[14:10:06]     color: RGB(0.75, 0.75, 0.75) [Opaque_191_191_191]
[14:10:06]     bbox: (0.0185 x 0.0190 x 0.0190) m
[14:10:06]   [LEAF] d=5 F6
[14:10:06]     path: wheel_2_link:1+Wheel_Hub:3+OmniWheelwithHub:1+Omni Wheel:1+A1_ASM:2+F6:1
[14:10:06]     global_pos: (-0.000000, 0.269287, -0.028962) m
[14:10:06]     mass: 0.000177 kg, bodies: 2
[14:10:06]     com_global: (-0.000000, 0.310787, -0.036962) m
[14:10:06]     com_component_local: (0.000000, 0.041500, -0.008000) m
[14:10:06]     inertia@origin: ixx=3.169158e-07 iyy=2.075227e-08 izz=3.147727e-07 kg·m²
[14:10:06]     inertia@com:    ixx=1.976377e-10 iyy=9.403421e-09 izz=9.403421e-09 kg·m²
[14:10:06]     material: Generic
[14:10:06]     color: RGB(0.31, 0.31, 0.31) [Default]
[14:10:06]     bbox: (0.0320 x 0.0035 x 0.0030) m
[14:10:06]   [LEAF] d=5 F5
[14:10:06]     path: wheel_2_link:1+Wheel_Hub:3+OmniWheelwithHub:1+Omni Wheel:1+A1_ASM:2+F5:2
[14:10:06]     global_pos: (-0.000000, 0.269287, -0.028962) m
[14:10:06]     mass: 0.004761 kg, bodies: 1
[14:10:06]     com_global: (-0.000000, 0.310787, -0.036962) m
[14:10:06]     com_component_local: (-0.000000, 0.041500, -0.008000) m
[14:10:06]     inertia@origin: ixx=8.717993e-06 iyy=5.403131e-07 izz=8.434997e-06 kg·m²
[14:10:06]     inertia@com:    ixx=2.138575e-07 iyy=2.355876e-07 izz=2.355876e-07 kg·m²
[14:10:06]     material: Generic
[14:10:06]     color: RGB(0.75, 0.75, 0.75) [Opaque_191_191_191]
[14:10:06]     bbox: (0.0185 x 0.0190 x 0.0190) m
[14:10:06]   [LEAF] d=5 F6
[14:10:06]     path: wheel_2_link:1+Wheel_Hub:3+OmniWheelwithHub:1+Omni Wheel:1+A1_ASM:2+F6:2
[14:10:06]     global_pos: (-0.000000, 0.269287, -0.028962) m
[14:10:06]     mass: 0.000177 kg, bodies: 2
[14:10:06]     com_global: (-0.000000, 0.310787, -0.036962) m
[14:10:06]     com_component_local: (0.000000, 0.041500, -0.008000) m
[14:10:06]     inertia@origin: ixx=3.169158e-07 iyy=2.075227e-08 izz=3.147727e-07 kg·m²
[14:10:06]     inertia@com:    ixx=1.976377e-10 iyy=9.403421e-09 izz=9.403421e-09 kg·m²
[14:10:06]     material: Generic
[14:10:06]     color: RGB(0.31, 0.31, 0.31) [Default]
[14:10:06]     bbox: (0.0320 x 0.0035 x 0.0030) m
[14:10:06]   [LEAF] d=5 F5
[14:10:06]     path: wheel_2_link:1+Wheel_Hub:3+OmniWheelwithHub:1+Omni Wheel:1+A1_ASM:2+F5:3
[14:10:06]     global_pos: (-0.000000, 0.269287, -0.028962) m
[14:10:06]     mass: 0.004761 kg, bodies: 1
[14:10:06]     com_global: (-0.000000, 0.310787, -0.036962) m
[14:10:06]     com_component_local: (-0.000000, 0.041500, -0.008000) m
[14:10:06]     inertia@origin: ixx=8.717993e-06 iyy=5.403131e-07 izz=8.434997e-06 kg·m²
[14:10:06]     inertia@com:    ixx=2.138575e-07 iyy=2.355876e-07 izz=2.355876e-07 kg·m²
[14:10:06]     material: Generic
[14:10:06]     color: RGB(0.75, 0.75, 0.75) [Opaque_191_191_191]
[14:10:06]     bbox: (0.0185 x 0.0190 x 0.0190) m
[14:10:06]   [LEAF] d=5 F6
[14:10:06]     path: wheel_2_link:1+Wheel_Hub:3+OmniWheelwithHub:1+Omni Wheel:1+A1_ASM:2+F6:3
[14:10:06]     global_pos: (-0.000000, 0.269287, -0.028962) m
[14:10:06]     mass: 0.000177 kg, bodies: 2
[14:10:06]     com_global: (-0.000000, 0.310787, -0.036962) m
[14:10:06]     com_component_local: (0.000000, 0.041500, -0.008000) m
[14:10:06]     inertia@origin: ixx=3.169158e-07 iyy=2.075227e-08 izz=3.147727e-07 kg·m²
[14:10:06]     inertia@com:    ixx=1.976377e-10 iyy=9.403421e-09 izz=9.403421e-09 kg·m²
[14:10:06]     material: Generic
[14:10:06]     color: RGB(0.31, 0.31, 0.31) [Default]
[14:10:06]     bbox: (0.0320 x 0.0035 x 0.0030) m
[14:10:06]   [LEAF] d=5 F5
[14:10:06]     path: wheel_2_link:1+Wheel_Hub:3+OmniWheelwithHub:1+Omni Wheel:1+A1_ASM:2+F5:4
[14:10:06]     global_pos: (-0.000000, 0.269287, -0.028962) m
[14:10:06]     mass: 0.004761 kg, bodies: 1
[14:10:06]     com_global: (-0.000000, 0.310787, -0.036962) m
[14:10:06]     com_component_local: (-0.000000, 0.041500, -0.008000) m
[14:10:06]     inertia@origin: ixx=8.717993e-06 iyy=5.403131e-07 izz=8.434997e-06 kg·m²
[14:10:06]     inertia@com:    ixx=2.138575e-07 iyy=2.355876e-07 izz=2.355876e-07 kg·m²
[14:10:06]     material: Generic
[14:10:06]     color: RGB(0.75, 0.75, 0.75) [Opaque_191_191_191]
[14:10:06]     bbox: (0.0185 x 0.0190 x 0.0190) m
[14:10:06]   [LEAF] d=5 F6
[14:10:06]     path: wheel_2_link:1+Wheel_Hub:3+OmniWheelwithHub:1+Omni Wheel:1+A1_ASM:2+F6:4
[14:10:06]     global_pos: (-0.000000, 0.269287, -0.028962) m
[14:10:06]     mass: 0.000177 kg, bodies: 2
[14:10:06]     com_global: (-0.000000, 0.310787, -0.036962) m
[14:10:06]     com_component_local: (0.000000, 0.041500, -0.008000) m
[14:10:06]     inertia@origin: ixx=3.169158e-07 iyy=2.075227e-08 izz=3.147727e-07 kg·m²
[14:10:06]     inertia@com:    ixx=1.976377e-10 iyy=9.403421e-09 izz=9.403421e-09 kg·m²
[14:10:06]     material: Generic
[14:10:06]     color: RGB(0.31, 0.31, 0.31) [Default]
[14:10:06]     bbox: (0.0320 x 0.0035 x 0.0030) m
[14:10:06]   [LEAF] d=5 F5
[14:10:06]     path: wheel_2_link:1+Wheel_Hub:3+OmniWheelwithHub:1+Omni Wheel:1+A1_ASM:2+F5:5
[14:10:06]     global_pos: (-0.000000, 0.269287, -0.028962) m
[14:10:06]     mass: 0.004761 kg, bodies: 1
[14:10:06]     com_global: (-0.000000, 0.310787, -0.036962) m
[14:10:06]     com_component_local: (-0.000000, 0.041500, -0.008000) m
[14:10:06]     inertia@origin: ixx=8.717993e-06 iyy=5.403131e-07 izz=8.434997e-06 kg·m²
[14:10:06]     inertia@com:    ixx=2.138575e-07 iyy=2.355876e-07 izz=2.355876e-07 kg·m²
[14:10:06]     material: Generic
[14:10:06]     color: RGB(0.75, 0.75, 0.75) [Opaque_191_191_191]
[14:10:06]     bbox: (0.0185 x 0.0190 x 0.0190) m
[14:10:06]   [LEAF] d=5 F6
[14:10:06]     path: wheel_2_link:1+Wheel_Hub:3+OmniWheelwithHub:1+Omni Wheel:1+A1_ASM:2+F6:5
[14:10:06]     global_pos: (-0.000000, 0.269287, -0.028962) m
[14:10:06]     mass: 0.000177 kg, bodies: 2
[14:10:06]     com_global: (-0.000000, 0.310787, -0.036962) m
[14:10:06]     com_component_local: (0.000000, 0.041500, -0.008000) m
[14:10:06]     inertia@origin: ixx=3.169158e-07 iyy=2.075227e-08 izz=3.147727e-07 kg·m²
[14:10:06]     inertia@com:    ixx=1.976377e-10 iyy=9.403421e-09 izz=9.403421e-09 kg·m²
[14:10:06]     material: Generic
[14:10:06]     color: RGB(0.31, 0.31, 0.31) [Default]
[14:10:06]     bbox: (0.0320 x 0.0035 x 0.0030) m
[14:10:06]   [LEAF] d=5 F5
[14:10:06]     path: wheel_2_link:1+Wheel_Hub:3+OmniWheelwithHub:1+Omni Wheel:1+A1_ASM:2+F5:6
[14:10:06]     global_pos: (-0.000000, 0.269287, -0.028962) m
[14:10:06]     mass: 0.004761 kg, bodies: 1
[14:10:06]     com_global: (-0.000000, 0.310787, -0.036962) m
[14:10:06]     com_component_local: (-0.000000, 0.041500, -0.008000) m
[14:10:06]     inertia@origin: ixx=8.717993e-06 iyy=5.403131e-07 izz=8.434997e-06 kg·m²
[14:10:06]     inertia@com:    ixx=2.138575e-07 iyy=2.355876e-07 izz=2.355876e-07 kg·m²
[14:10:06]     material: Generic
[14:10:06]     color: RGB(0.75, 0.75, 0.75) [Opaque_191_191_191]
[14:10:06]     bbox: (0.0185 x 0.0190 x 0.0190) m
[14:10:06]   [LEAF] d=5 F6
[14:10:06]     path: wheel_2_link:1+Wheel_Hub:3+OmniWheelwithHub:1+Omni Wheel:1+A1_ASM:2+F6:6
[14:10:06]     global_pos: (-0.000000, 0.269287, -0.028962) m
[14:10:06]     mass: 0.000177 kg, bodies: 2
[14:10:06]     com_global: (-0.000000, 0.310787, -0.036962) m
[14:10:06]     com_component_local: (0.000000, 0.041500, -0.008000) m
[14:10:06]     inertia@origin: ixx=3.169158e-07 iyy=2.075227e-08 izz=3.147727e-07 kg·m²
[14:10:06]     inertia@com:    ixx=1.976377e-10 iyy=9.403421e-09 izz=9.403421e-09 kg·m²
[14:10:06]     material: Generic
[14:10:06]     color: RGB(0.31, 0.31, 0.31) [Default]
[14:10:06]     bbox: (0.0320 x 0.0035 x 0.0030) m
[14:10:06]   [LEAF] d=5 F5
[14:10:06]     path: wheel_2_link:1+Wheel_Hub:3+OmniWheelwithHub:1+Omni Wheel:1+A1_ASM:2+F5:7
[14:10:06]     global_pos: (-0.000000, 0.269287, -0.028962) m
[14:10:06]     mass: 0.004761 kg, bodies: 1
[14:10:06]     com_global: (-0.000000, 0.310787, -0.036962) m
[14:10:06]     com_component_local: (-0.000000, 0.041500, -0.008000) m
[14:10:06]     inertia@origin: ixx=8.717993e-06 iyy=5.403131e-07 izz=8.434997e-06 kg·m²
[14:10:06]     inertia@com:    ixx=2.138575e-07 iyy=2.355876e-07 izz=2.355876e-07 kg·m²
[14:10:06]     material: Generic
[14:10:06]     color: RGB(0.75, 0.75, 0.75) [Opaque_191_191_191]
[14:10:06]     bbox: (0.0185 x 0.0190 x 0.0190) m
[14:10:06]   [LEAF] d=5 F6
[14:10:06]     path: wheel_2_link:1+Wheel_Hub:3+OmniWheelwithHub:1+Omni Wheel:1+A1_ASM:2+F6:7
[14:10:06]     global_pos: (-0.000000, 0.269287, -0.028962) m
[14:10:06]     mass: 0.000177 kg, bodies: 2
[14:10:06]     com_global: (-0.000000, 0.310787, -0.036962) m
[14:10:06]     com_component_local: (0.000000, 0.041500, -0.008000) m
[14:10:06]     inertia@origin: ixx=3.169158e-07 iyy=2.075227e-08 izz=3.147727e-07 kg·m²
[14:10:06]     inertia@com:    ixx=1.976377e-10 iyy=9.403421e-09 izz=9.403421e-09 kg·m²
[14:10:06]     material: Generic
[14:10:06]     color: RGB(0.31, 0.31, 0.31) [Default]
[14:10:06]     bbox: (0.0320 x 0.0035 x 0.0030) m
[14:10:06]   [LEAF] d=5 F5
[14:10:06]     path: wheel_2_link:1+Wheel_Hub:3+OmniWheelwithHub:1+Omni Wheel:1+A1_ASM:2+F5:8
[14:10:06]     global_pos: (-0.000000, 0.269287, -0.028962) m
[14:10:06]     mass: 0.004761 kg, bodies: 1
[14:10:06]     com_global: (-0.000000, 0.310787, -0.036962) m
[14:10:06]     com_component_local: (-0.000000, 0.041500, -0.008000) m
[14:10:06]     inertia@origin: ixx=8.717993e-06 iyy=5.403131e-07 izz=8.434997e-06 kg·m²
[14:10:06]     inertia@com:    ixx=2.138575e-07 iyy=2.355876e-07 izz=2.355876e-07 kg·m²
[14:10:06]     material: Generic
[14:10:06]     color: RGB(0.75, 0.75, 0.75) [Opaque_191_191_191]
[14:10:06]     bbox: (0.0185 x 0.0190 x 0.0190) m
[14:10:06]   [LEAF] d=5 F6
[14:10:06]     path: wheel_2_link:1+Wheel_Hub:3+OmniWheelwithHub:1+Omni Wheel:1+A1_ASM:2+F6:8
[14:10:06]     global_pos: (-0.000000, 0.269287, -0.028962) m
[14:10:06]     mass: 0.000177 kg, bodies: 2
[14:10:06]     com_global: (-0.000000, 0.310787, -0.036962) m
[14:10:06]     com_component_local: (0.000000, 0.041500, -0.008000) m
[14:10:06]     inertia@origin: ixx=3.169158e-07 iyy=2.075227e-08 izz=3.147727e-07 kg·m²
[14:10:06]     inertia@com:    ixx=1.976377e-10 iyy=9.403421e-09 izz=9.403421e-09 kg·m²
[14:10:06]     material: Generic
[14:10:06]     color: RGB(0.31, 0.31, 0.31) [Default]
[14:10:06]     bbox: (0.0320 x 0.0035 x 0.0030) m
[14:10:06]   [LEAF] d=5 F5
[14:10:06]     path: wheel_2_link:1+Wheel_Hub:3+OmniWheelwithHub:1+Omni Wheel:1+A1_ASM:2+F5:9
[14:10:06]     global_pos: (-0.000000, 0.269287, -0.028962) m
[14:10:06]     mass: 0.004761 kg, bodies: 1
[14:10:06]     com_global: (-0.000000, 0.310787, -0.036962) m
[14:10:06]     com_component_local: (-0.000000, 0.041500, -0.008000) m
[14:10:06]     inertia@origin: ixx=8.717993e-06 iyy=5.403131e-07 izz=8.434997e-06 kg·m²
[14:10:06]     inertia@com:    ixx=2.138575e-07 iyy=2.355876e-07 izz=2.355876e-07 kg·m²
[14:10:06]     material: Generic
[14:10:06]     color: RGB(0.75, 0.75, 0.75) [Opaque_191_191_191]
[14:10:06]     bbox: (0.0185 x 0.0190 x 0.0190) m
[14:10:06]   [LEAF] d=5 F6
[14:10:06]     path: wheel_2_link:1+Wheel_Hub:3+OmniWheelwithHub:1+Omni Wheel:1+A1_ASM:2+F6:9
[14:10:06]     global_pos: (-0.000000, 0.269287, -0.028962) m
[14:10:06]     mass: 0.000177 kg, bodies: 2
[14:10:06]     com_global: (-0.000000, 0.310787, -0.036962) m
[14:10:06]     com_component_local: (0.000000, 0.041500, -0.008000) m
[14:10:06]     inertia@origin: ixx=3.169158e-07 iyy=2.075227e-08 izz=3.147727e-07 kg·m²
[14:10:06]     inertia@com:    ixx=1.976377e-10 iyy=9.403421e-09 izz=9.403421e-09 kg·m²
[14:10:06]     material: Generic
[14:10:06]     color: RGB(0.31, 0.31, 0.31) [Default]
[14:10:06]     bbox: (0.0320 x 0.0035 x 0.0030) m
[14:10:06]   [LEAF] d=5 F2
[14:10:06]     path: wheel_2_link:1+Wheel_Hub:3+OmniWheelwithHub:1+Omni Wheel:1+A1_ASM:2+F2:2
[14:10:06]     global_pos: (-0.000000, 0.285288, -0.028962) m
[14:10:06]     mass: 0.021208 kg, bodies: 1
[14:10:06]     com_global: (0.000030, 0.285288, -0.040323) m
[14:10:06]     com_component_local: (0.000030, 0.000000, -0.011361) m
[14:10:06]     inertia@origin: ixx=1.263883e-05 iyy=1.263752e-05 izz=1.962197e-05 kg·m²
[14:10:06]     inertia@com:    ixx=9.901373e-06 iyy=9.900039e-06 izz=1.962195e-05 kg·m²
[14:10:06]     material: Generic
[14:10:06]     color: RGB(0.75, 0.75, 0.75) [Opaque_191_191_191]
[14:10:06]     bbox: (0.0945 x 0.0933 x 0.0100) m
[14:10:06]   [SUBASM] d=4 A1_ASM
[14:10:06]     path: wheel_2_link:1+Wheel_Hub:3+OmniWheelwithHub:1+Omni Wheel:1+A1_ASM:2
[14:10:06]     global_pos: (-0.000000, 0.269287, -0.028962) m
[14:10:06]   [SUBASM] d=3 Omni_Wheel
[14:10:06]     path: wheel_2_link:1+Wheel_Hub:3+OmniWheelwithHub:1+Omni Wheel:1
[14:10:06]     global_pos: (-0.000000, 0.305689, -0.028962) m
[14:10:06]   [LEAF] d=3 6mm_Mount
[14:10:06]     path: wheel_2_link:1+Wheel_Hub:3+OmniWheelwithHub:1+6mm_Mount:1
[14:10:06]     global_pos: (-0.000000, 0.285189, -0.028962) m
[14:10:06]     mass: 0.006982 kg, bodies: 1
[14:10:06]     com_global: (0.000046, 0.298476, -0.029008) m
[14:10:06]     com_component_local: (0.000046, 0.013287, -0.000046) m
[14:10:06]     inertia@origin: ixx=1.824828e-06 iyy=3.446660e-07 izz=1.824829e-06 kg·m²
[14:10:06]     inertia@com:    ixx=5.920723e-07 iyy=3.446366e-07 izz=5.920737e-07 kg·m²
[14:10:06]     material: Generic
[14:10:06]     color: RGB(0.75, 0.75, 0.75) [Opaque_191_191_191]
[14:10:06]     bbox: (0.0218 x 0.0295 x 0.0218) m
[14:10:06]   [LEAF] d=3 Back_Spacer
[14:10:06]     path: wheel_2_link:1+Wheel_Hub:3+OmniWheelwithHub:1+Back Spacer:1
[14:10:06]     global_pos: (-0.000000, 0.284288, -0.028962) m
[14:10:06]     mass: 0.002393 kg, bodies: 1
[14:10:06]     com_global: (-0.000000, 0.287788, -0.028962) m
[14:10:06]     com_component_local: (-0.000000, 0.003500, 0.000000) m
[14:10:06]     inertia@origin: ixx=1.150960e-07 iyy=1.523277e-07 izz=1.150960e-07 kg·m²
[14:10:06]     inertia@com:    ixx=8.578160e-08 iyy=1.523277e-07 izz=8.578158e-08 kg·m²
[14:10:06]     material: Generic
[14:10:06]     color: RGB(0.75, 0.75, 0.75) [Opaque_191_191_191]
[14:10:06]     bbox: (0.0218 x 0.0070 x 0.0218) m
[14:10:06]   [SUBASM] d=2 OmniWheelwithHub
[14:10:06]     path: wheel_2_link:1+Wheel_Hub:3+OmniWheelwithHub:1
[14:10:06]     global_pos: (-0.006753, 0.227656, -0.019756) m
[14:10:06]   [LEAF] d=2 Motor_Hub
[14:10:06]     path: wheel_2_link:1+Wheel_Hub:3+Motor_Hub:1
[14:10:06]     global_pos: (-0.000000, 0.270287, -0.028962) m
[14:10:06]     mass: 0.118971 kg, bodies: 1
[14:10:06]     com_global: (0.000000, 0.270287, -0.025341) m
[14:10:06]     com_component_local: (0.000000, 0.000000, 0.003621) m
[14:10:06]     inertia@origin: ixx=2.302890e-05 iyy=2.302891e-05 izz=4.124951e-05 kg·m²
[14:10:06]     inertia@com:    ixx=2.146927e-05 iyy=2.146928e-05 izz=4.124951e-05 kg·m²
[14:10:06]     material: Steel
[14:10:06]     color: RGB(0.07, 0.13, 0.50) [ABS_White_1]
[14:10:06]     bbox: (0.0576 x 0.0576 x 0.0110) m
[14:10:06]   [SUBASM] d=1 Wheel_Hub
[14:10:06]     path: wheel_2_link:1+Wheel_Hub:3
[14:10:06]     global_pos: (-0.000000, 0.270287, -0.028962) m
[14:10:06]   [SUBASM] d=0 wheel_2_link
[14:10:06]     path: wheel_2_link:1
[14:10:06]     global_pos: (0.000000, 0.000000, 0.000000) m
[14:10:06]   [LEAF] d=1 Omni_Wheel
[14:10:06]     path: wheel_3_link:1+Omni_Wheel:2
[14:10:06]     global_pos: (0.001943, 0.133940, -0.621278) m
[14:10:06]     mass: 1.479811 kg, bodies: 60
[14:10:06]     com_global: (-0.015376, 0.017609, 0.071746) m
[14:10:06]     com_component_local: (-0.017319, -0.116331, 0.693024) m
[14:10:06]     inertia@origin: ixx=7.324645e-01 iyy=7.122855e-01 izz=2.176439e-02 kg·m²
[14:10:06]     inertia@com:    ixx=1.711535e-03 iyy=1.114997e-03 izz=1.294264e-03 kg·m²
[14:10:06]     material: Steel
[14:10:06]     color: RGB(0.37, 0.42, 0.51) [PA_12_Nylon_PA_603_CF_with_EOS_P_3D_Printers]
[14:10:06]     bbox: (0.0766 x 0.1022 x 0.1017) m
[14:10:06]   [LEAF] d=5 F2
[14:10:06]     path: wheel_3_link:1+Wheel_Hub:1+OmniWheelwithHub:1+Omni Wheel:1+A1_ASM:1+F2:1
[14:10:06]     global_pos: (-0.264734, -0.152844, -0.028962) m
[14:10:06]     mass: 0.021208 kg, bodies: 1
[14:10:06]     com_global: (-0.264704, -0.152844, -0.040323) m
[14:10:06]     com_component_local: (0.000030, 0.000000, -0.011361) m
[14:10:06]     inertia@origin: ixx=1.263883e-05 iyy=1.263752e-05 izz=1.962197e-05 kg·m²
[14:10:06]     inertia@com:    ixx=9.901373e-06 iyy=9.900039e-06 izz=1.962195e-05 kg·m²
[14:10:06]     material: Generic
[14:10:06]     color: RGB(0.75, 0.75, 0.75) [Opaque_191_191_191]
[14:10:06]     bbox: (0.0945 x 0.0933 x 0.0100) m
[14:10:06]   [LEAF] d=5 F5
[14:10:06]     path: wheel_3_link:1+Wheel_Hub:1+OmniWheelwithHub:1+Omni Wheel:1+A1_ASM:1+F5:1
[14:10:06]     global_pos: (-0.264734, -0.152844, -0.028962) m
[14:10:06]     mass: 0.004761 kg, bodies: 1
[14:10:06]     com_global: (-0.264734, -0.111344, -0.036962) m
[14:10:06]     com_component_local: (-0.000000, 0.041500, -0.008000) m
[14:10:06]     inertia@origin: ixx=8.717993e-06 iyy=5.403131e-07 izz=8.434997e-06 kg·m²
[14:10:06]     inertia@com:    ixx=2.138575e-07 iyy=2.355876e-07 izz=2.355876e-07 kg·m²
[14:10:06]     material: Generic
[14:10:06]     color: RGB(0.75, 0.75, 0.75) [Opaque_191_191_191]
[14:10:06]     bbox: (0.0185 x 0.0190 x 0.0190) m
[14:10:06]   [LEAF] d=5 F6
[14:10:06]     path: wheel_3_link:1+Wheel_Hub:1+OmniWheelwithHub:1+Omni Wheel:1+A1_ASM:1+F6:1
[14:10:06]     global_pos: (-0.264734, -0.152844, -0.028962) m
[14:10:06]     mass: 0.000177 kg, bodies: 2
[14:10:06]     com_global: (-0.264734, -0.111344, -0.036962) m
[14:10:06]     com_component_local: (0.000000, 0.041500, -0.008000) m
[14:10:06]     inertia@origin: ixx=3.169158e-07 iyy=2.075227e-08 izz=3.147727e-07 kg·m²
[14:10:06]     inertia@com:    ixx=1.976377e-10 iyy=9.403421e-09 izz=9.403421e-09 kg·m²
[14:10:06]     material: Generic
[14:10:06]     color: RGB(0.31, 0.31, 0.31) [Default]
[14:10:06]     bbox: (0.0320 x 0.0035 x 0.0030) m
[14:10:06]   [LEAF] d=5 F5
[14:10:06]     path: wheel_3_link:1+Wheel_Hub:1+OmniWheelwithHub:1+Omni Wheel:1+A1_ASM:1+F5:2
[14:10:06]     global_pos: (-0.264734, -0.152844, -0.028962) m
[14:10:06]     mass: 0.004761 kg, bodies: 1
[14:10:06]     com_global: (-0.264734, -0.111344, -0.036962) m
[14:10:06]     com_component_local: (-0.000000, 0.041500, -0.008000) m
[14:10:06]     inertia@origin: ixx=8.717993e-06 iyy=5.403131e-07 izz=8.434997e-06 kg·m²
[14:10:06]     inertia@com:    ixx=2.138575e-07 iyy=2.355876e-07 izz=2.355876e-07 kg·m²
[14:10:06]     material: Generic
[14:10:06]     color: RGB(0.75, 0.75, 0.75) [Opaque_191_191_191]
[14:10:06]     bbox: (0.0185 x 0.0190 x 0.0190) m
[14:10:06]   [LEAF] d=5 F6
[14:10:06]     path: wheel_3_link:1+Wheel_Hub:1+OmniWheelwithHub:1+Omni Wheel:1+A1_ASM:1+F6:2
[14:10:06]     global_pos: (-0.264734, -0.152844, -0.028962) m
[14:10:06]     mass: 0.000177 kg, bodies: 2
[14:10:06]     com_global: (-0.264734, -0.111344, -0.036962) m
[14:10:06]     com_component_local: (0.000000, 0.041500, -0.008000) m
[14:10:06]     inertia@origin: ixx=3.169158e-07 iyy=2.075227e-08 izz=3.147727e-07 kg·m²
[14:10:06]     inertia@com:    ixx=1.976377e-10 iyy=9.403421e-09 izz=9.403421e-09 kg·m²
[14:10:06]     material: Generic
[14:10:06]     color: RGB(0.31, 0.31, 0.31) [Default]
[14:10:06]     bbox: (0.0320 x 0.0035 x 0.0030) m
[14:10:06]   [LEAF] d=5 F5
[14:10:06]     path: wheel_3_link:1+Wheel_Hub:1+OmniWheelwithHub:1+Omni Wheel:1+A1_ASM:1+F5:3
[14:10:06]     global_pos: (-0.264734, -0.152844, -0.028962) m
[14:10:06]     mass: 0.004761 kg, bodies: 1
[14:10:06]     com_global: (-0.264734, -0.111344, -0.036962) m
[14:10:06]     com_component_local: (-0.000000, 0.041500, -0.008000) m
[14:10:06]     inertia@origin: ixx=8.717993e-06 iyy=5.403131e-07 izz=8.434997e-06 kg·m²
[14:10:06]     inertia@com:    ixx=2.138575e-07 iyy=2.355876e-07 izz=2.355876e-07 kg·m²
[14:10:06]     material: Generic
[14:10:06]     color: RGB(0.75, 0.75, 0.75) [Opaque_191_191_191]
[14:10:06]     bbox: (0.0185 x 0.0190 x 0.0190) m
[14:10:06]   [LEAF] d=5 F6
[14:10:06]     path: wheel_3_link:1+Wheel_Hub:1+OmniWheelwithHub:1+Omni Wheel:1+A1_ASM:1+F6:3
[14:10:06]     global_pos: (-0.264734, -0.152844, -0.028962) m
[14:10:06]     mass: 0.000177 kg, bodies: 2
[14:10:06]     com_global: (-0.264734, -0.111344, -0.036962) m
[14:10:06]     com_component_local: (0.000000, 0.041500, -0.008000) m
[14:10:06]     inertia@origin: ixx=3.169158e-07 iyy=2.075227e-08 izz=3.147727e-07 kg·m²
[14:10:06]     inertia@com:    ixx=1.976377e-10 iyy=9.403421e-09 izz=9.403421e-09 kg·m²
[14:10:06]     material: Generic
[14:10:06]     color: RGB(0.31, 0.31, 0.31) [Default]
[14:10:06]     bbox: (0.0320 x 0.0035 x 0.0030) m
[14:10:06]   [LEAF] d=5 F5
[14:10:06]     path: wheel_3_link:1+Wheel_Hub:1+OmniWheelwithHub:1+Omni Wheel:1+A1_ASM:1+F5:4
[14:10:06]     global_pos: (-0.264734, -0.152844, -0.028962) m
[14:10:06]     mass: 0.004761 kg, bodies: 1
[14:10:06]     com_global: (-0.264734, -0.111344, -0.036962) m
[14:10:06]     com_component_local: (-0.000000, 0.041500, -0.008000) m
[14:10:06]     inertia@origin: ixx=8.717993e-06 iyy=5.403131e-07 izz=8.434997e-06 kg·m²
[14:10:06]     inertia@com:    ixx=2.138575e-07 iyy=2.355876e-07 izz=2.355876e-07 kg·m²
[14:10:06]     material: Generic
[14:10:06]     color: RGB(0.75, 0.75, 0.75) [Opaque_191_191_191]
[14:10:06]     bbox: (0.0185 x 0.0190 x 0.0190) m
[14:10:06]   [LEAF] d=5 F6
[14:10:06]     path: wheel_3_link:1+Wheel_Hub:1+OmniWheelwithHub:1+Omni Wheel:1+A1_ASM:1+F6:4
[14:10:06]     global_pos: (-0.264734, -0.152844, -0.028962) m
[14:10:06]     mass: 0.000177 kg, bodies: 2
[14:10:06]     com_global: (-0.264734, -0.111344, -0.036962) m
[14:10:06]     com_component_local: (0.000000, 0.041500, -0.008000) m
[14:10:06]     inertia@origin: ixx=3.169158e-07 iyy=2.075227e-08 izz=3.147727e-07 kg·m²
[14:10:06]     inertia@com:    ixx=1.976377e-10 iyy=9.403421e-09 izz=9.403421e-09 kg·m²
[14:10:06]     material: Generic
[14:10:06]     color: RGB(0.31, 0.31, 0.31) [Default]
[14:10:06]     bbox: (0.0320 x 0.0035 x 0.0030) m
[14:10:06]   [LEAF] d=5 F5
[14:10:06]     path: wheel_3_link:1+Wheel_Hub:1+OmniWheelwithHub:1+Omni Wheel:1+A1_ASM:1+F5:5
[14:10:06]     global_pos: (-0.264734, -0.152844, -0.028962) m
[14:10:06]     mass: 0.004761 kg, bodies: 1
[14:10:06]     com_global: (-0.264734, -0.111344, -0.036962) m
[14:10:06]     com_component_local: (-0.000000, 0.041500, -0.008000) m
[14:10:06]     inertia@origin: ixx=8.717993e-06 iyy=5.403131e-07 izz=8.434997e-06 kg·m²
[14:10:06]     inertia@com:    ixx=2.138575e-07 iyy=2.355876e-07 izz=2.355876e-07 kg·m²
[14:10:06]     material: Generic
[14:10:06]     color: RGB(0.75, 0.75, 0.75) [Opaque_191_191_191]
[14:10:06]     bbox: (0.0185 x 0.0190 x 0.0190) m
[14:10:06]   [LEAF] d=5 F6
[14:10:06]     path: wheel_3_link:1+Wheel_Hub:1+OmniWheelwithHub:1+Omni Wheel:1+A1_ASM:1+F6:5
[14:10:06]     global_pos: (-0.264734, -0.152844, -0.028962) m
[14:10:06]     mass: 0.000177 kg, bodies: 2
[14:10:06]     com_global: (-0.264734, -0.111344, -0.036962) m
[14:10:06]     com_component_local: (0.000000, 0.041500, -0.008000) m
[14:10:06]     inertia@origin: ixx=3.169158e-07 iyy=2.075227e-08 izz=3.147727e-07 kg·m²
[14:10:06]     inertia@com:    ixx=1.976377e-10 iyy=9.403421e-09 izz=9.403421e-09 kg·m²
[14:10:06]     material: Generic
[14:10:06]     color: RGB(0.31, 0.31, 0.31) [Default]
[14:10:06]     bbox: (0.0320 x 0.0035 x 0.0030) m
[14:10:06]   [LEAF] d=5 F5
[14:10:06]     path: wheel_3_link:1+Wheel_Hub:1+OmniWheelwithHub:1+Omni Wheel:1+A1_ASM:1+F5:6
[14:10:06]     global_pos: (-0.264734, -0.152844, -0.028962) m
[14:10:06]     mass: 0.004761 kg, bodies: 1
[14:10:06]     com_global: (-0.264734, -0.111344, -0.036962) m
[14:10:06]     com_component_local: (-0.000000, 0.041500, -0.008000) m
[14:10:06]     inertia@origin: ixx=8.717993e-06 iyy=5.403131e-07 izz=8.434997e-06 kg·m²
[14:10:06]     inertia@com:    ixx=2.138575e-07 iyy=2.355876e-07 izz=2.355876e-07 kg·m²
[14:10:06]     material: Generic
[14:10:06]     color: RGB(0.75, 0.75, 0.75) [Opaque_191_191_191]
[14:10:06]     bbox: (0.0185 x 0.0190 x 0.0190) m
[14:10:06]   [LEAF] d=5 F6
[14:10:06]     path: wheel_3_link:1+Wheel_Hub:1+OmniWheelwithHub:1+Omni Wheel:1+A1_ASM:1+F6:6
[14:10:06]     global_pos: (-0.264734, -0.152844, -0.028962) m
[14:10:06]     mass: 0.000177 kg, bodies: 2
[14:10:06]     com_global: (-0.264734, -0.111344, -0.036962) m
[14:10:06]     com_component_local: (0.000000, 0.041500, -0.008000) m
[14:10:06]     inertia@origin: ixx=3.169158e-07 iyy=2.075227e-08 izz=3.147727e-07 kg·m²
[14:10:06]     inertia@com:    ixx=1.976377e-10 iyy=9.403421e-09 izz=9.403421e-09 kg·m²
[14:10:06]     material: Generic
[14:10:06]     color: RGB(0.31, 0.31, 0.31) [Default]
[14:10:06]     bbox: (0.0320 x 0.0035 x 0.0030) m
[14:10:06]   [LEAF] d=5 F5
[14:10:06]     path: wheel_3_link:1+Wheel_Hub:1+OmniWheelwithHub:1+Omni Wheel:1+A1_ASM:1+F5:7
[14:10:06]     global_pos: (-0.264734, -0.152844, -0.028962) m
[14:10:06]     mass: 0.004761 kg, bodies: 1
[14:10:06]     com_global: (-0.264734, -0.111344, -0.036962) m
[14:10:06]     com_component_local: (-0.000000, 0.041500, -0.008000) m
[14:10:06]     inertia@origin: ixx=8.717993e-06 iyy=5.403131e-07 izz=8.434997e-06 kg·m²
[14:10:06]     inertia@com:    ixx=2.138575e-07 iyy=2.355876e-07 izz=2.355876e-07 kg·m²
[14:10:06]     material: Generic
[14:10:06]     color: RGB(0.75, 0.75, 0.75) [Opaque_191_191_191]
[14:10:06]     bbox: (0.0185 x 0.0190 x 0.0190) m
[14:10:06]   [LEAF] d=5 F6
[14:10:06]     path: wheel_3_link:1+Wheel_Hub:1+OmniWheelwithHub:1+Omni Wheel:1+A1_ASM:1+F6:7
[14:10:06]     global_pos: (-0.264734, -0.152844, -0.028962) m
[14:10:06]     mass: 0.000177 kg, bodies: 2
[14:10:06]     com_global: (-0.264734, -0.111344, -0.036962) m
[14:10:06]     com_component_local: (0.000000, 0.041500, -0.008000) m
[14:10:06]     inertia@origin: ixx=3.169158e-07 iyy=2.075227e-08 izz=3.147727e-07 kg·m²
[14:10:06]     inertia@com:    ixx=1.976377e-10 iyy=9.403421e-09 izz=9.403421e-09 kg·m²
[14:10:06]     material: Generic
[14:10:06]     color: RGB(0.31, 0.31, 0.31) [Default]
[14:10:06]     bbox: (0.0320 x 0.0035 x 0.0030) m
[14:10:06]   [LEAF] d=5 F5
[14:10:06]     path: wheel_3_link:1+Wheel_Hub:1+OmniWheelwithHub:1+Omni Wheel:1+A1_ASM:1+F5:8
[14:10:06]     global_pos: (-0.264734, -0.152844, -0.028962) m
[14:10:06]     mass: 0.004761 kg, bodies: 1
[14:10:06]     com_global: (-0.264734, -0.111344, -0.036962) m
[14:10:06]     com_component_local: (-0.000000, 0.041500, -0.008000) m
[14:10:06]     inertia@origin: ixx=8.717993e-06 iyy=5.403131e-07 izz=8.434997e-06 kg·m²
[14:10:06]     inertia@com:    ixx=2.138575e-07 iyy=2.355876e-07 izz=2.355876e-07 kg·m²
[14:10:06]     material: Generic
[14:10:06]     color: RGB(0.75, 0.75, 0.75) [Opaque_191_191_191]
[14:10:06]     bbox: (0.0185 x 0.0190 x 0.0190) m
[14:10:06]   [LEAF] d=5 F6
[14:10:06]     path: wheel_3_link:1+Wheel_Hub:1+OmniWheelwithHub:1+Omni Wheel:1+A1_ASM:1+F6:8
[14:10:06]     global_pos: (-0.264734, -0.152844, -0.028962) m
[14:10:06]     mass: 0.000177 kg, bodies: 2
[14:10:06]     com_global: (-0.264734, -0.111344, -0.036962) m
[14:10:06]     com_component_local: (0.000000, 0.041500, -0.008000) m
[14:10:06]     inertia@origin: ixx=3.169158e-07 iyy=2.075227e-08 izz=3.147727e-07 kg·m²
[14:10:06]     inertia@com:    ixx=1.976377e-10 iyy=9.403421e-09 izz=9.403421e-09 kg·m²
[14:10:06]     material: Generic
[14:10:06]     color: RGB(0.31, 0.31, 0.31) [Default]
[14:10:06]     bbox: (0.0320 x 0.0035 x 0.0030) m
[14:10:06]   [LEAF] d=5 F5
[14:10:06]     path: wheel_3_link:1+Wheel_Hub:1+OmniWheelwithHub:1+Omni Wheel:1+A1_ASM:1+F5:9
[14:10:06]     global_pos: (-0.264734, -0.152844, -0.028962) m
[14:10:06]     mass: 0.004761 kg, bodies: 1
[14:10:06]     com_global: (-0.264734, -0.111344, -0.036962) m
[14:10:06]     com_component_local: (-0.000000, 0.041500, -0.008000) m
[14:10:06]     inertia@origin: ixx=8.717993e-06 iyy=5.403131e-07 izz=8.434997e-06 kg·m²
[14:10:06]     inertia@com:    ixx=2.138575e-07 iyy=2.355876e-07 izz=2.355876e-07 kg·m²
[14:10:06]     material: Generic
[14:10:06]     color: RGB(0.75, 0.75, 0.75) [Opaque_191_191_191]
[14:10:06]     bbox: (0.0185 x 0.0190 x 0.0190) m
[14:10:06]   [LEAF] d=5 F6
[14:10:06]     path: wheel_3_link:1+Wheel_Hub:1+OmniWheelwithHub:1+Omni Wheel:1+A1_ASM:1+F6:9
[14:10:06]     global_pos: (-0.264734, -0.152844, -0.028962) m
[14:10:06]     mass: 0.000177 kg, bodies: 2
[14:10:06]     com_global: (-0.264734, -0.111344, -0.036962) m
[14:10:06]     com_component_local: (0.000000, 0.041500, -0.008000) m
[14:10:06]     inertia@origin: ixx=3.169158e-07 iyy=2.075227e-08 izz=3.147727e-07 kg·m²
[14:10:06]     inertia@com:    ixx=1.976377e-10 iyy=9.403421e-09 izz=9.403421e-09 kg·m²
[14:10:06]     material: Generic
[14:10:06]     color: RGB(0.31, 0.31, 0.31) [Default]
[14:10:06]     bbox: (0.0320 x 0.0035 x 0.0030) m
[14:10:06]   [LEAF] d=5 F2
[14:10:06]     path: wheel_3_link:1+Wheel_Hub:1+OmniWheelwithHub:1+Omni Wheel:1+A1_ASM:1+F2:2
[14:10:06]     global_pos: (-0.250877, -0.144844, -0.028962) m
[14:10:06]     mass: 0.021208 kg, bodies: 1
[14:10:06]     com_global: (-0.250847, -0.144844, -0.040323) m
[14:10:06]     com_component_local: (0.000030, 0.000000, -0.011361) m
[14:10:06]     inertia@origin: ixx=1.263883e-05 iyy=1.263752e-05 izz=1.962197e-05 kg·m²
[14:10:06]     inertia@com:    ixx=9.901373e-06 iyy=9.900039e-06 izz=1.962195e-05 kg·m²
[14:10:06]     material: Generic
[14:10:06]     color: RGB(0.75, 0.75, 0.75) [Opaque_191_191_191]
[14:10:06]     bbox: (0.0945 x 0.0933 x 0.0100) m
[14:10:06]   [SUBASM] d=4 A1_ASM
[14:10:06]     path: wheel_3_link:1+Wheel_Hub:1+OmniWheelwithHub:1+Omni Wheel:1+A1_ASM:1
[14:10:06]     global_pos: (-0.264734, -0.152844, -0.028962) m
[14:10:06]   [LEAF] d=4 F12
[14:10:06]     path: wheel_3_link:1+Wheel_Hub:1+OmniWheelwithHub:1+Omni Wheel:1+F12:1
[14:10:06]     global_pos: (-0.264734, -0.152844, -0.028962) m
[14:10:06]     mass: 0.012397 kg, bodies: 1
[14:10:06]     com_global: (-0.264734, -0.152844, -0.046210) m
[14:10:06]     com_component_local: (0.000000, -0.000000, -0.017248) m
[14:10:06]     inertia@origin: ixx=6.165417e-06 iyy=6.165417e-06 izz=4.749610e-06 kg·m²
[14:10:06]     inertia@com:    ixx=2.477412e-06 iyy=2.477413e-06 izz=4.749610e-06 kg·m²
[14:10:06]     material: Generic
[14:10:06]     color: RGB(0.75, 0.75, 0.75) [Opaque_191_191_191]
[14:10:06]     bbox: (0.0567 x 0.0567 x 0.0134) m
[14:10:06]   [LEAF] d=5 F2
[14:10:06]     path: wheel_3_link:1+Wheel_Hub:1+OmniWheelwithHub:1+Omni Wheel:1+A1_ASM:2+F2:1
[14:10:06]     global_pos: (-0.233210, -0.134644, -0.028962) m
[14:10:06]     mass: 0.021208 kg, bodies: 1
[14:10:06]     com_global: (-0.233179, -0.134644, -0.040323) m
[14:10:06]     com_component_local: (0.000030, 0.000000, -0.011361) m
[14:10:06]     inertia@origin: ixx=1.263883e-05 iyy=1.263752e-05 izz=1.962197e-05 kg·m²
[14:10:06]     inertia@com:    ixx=9.901373e-06 iyy=9.900039e-06 izz=1.962195e-05 kg·m²
[14:10:06]     material: Generic
[14:10:06]     color: RGB(0.75, 0.75, 0.75) [Opaque_191_191_191]
[14:10:06]     bbox: (0.0945 x 0.0933 x 0.0100) m
[14:10:06]   [LEAF] d=5 F5
[14:10:06]     path: wheel_3_link:1+Wheel_Hub:1+OmniWheelwithHub:1+Omni Wheel:1+A1_ASM:2+F5:1
[14:10:06]     global_pos: (-0.233210, -0.134644, -0.028962) m
[14:10:06]     mass: 0.004761 kg, bodies: 1
[14:10:06]     com_global: (-0.233210, -0.093144, -0.036962) m
[14:10:06]     com_component_local: (-0.000000, 0.041500, -0.008000) m
[14:10:06]     inertia@origin: ixx=8.717993e-06 iyy=5.403131e-07 izz=8.434997e-06 kg·m²
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

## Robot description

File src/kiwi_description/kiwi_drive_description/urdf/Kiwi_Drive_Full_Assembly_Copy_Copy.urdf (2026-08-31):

<?xml version="1.0"?>
<robot name="Kiwi_Drive_Full_Assembly_Copy_Copy">

  <!-- Materials -->
  <material name="Steel">
    <color rgba="1.000 1.000 1.000 1.0"/>
  </material>

  <link name="base_link">
    <inertial>
      <origin xyz="-0.001614 -0.001503 0.068862" rpy="0 0 0"/>
      <mass value="11.692090"/>
      <inertia ixx="3.367127e-01" ixy="-2.167779e-03" ixz="-1.508411e-03" iyy="3.398233e-01" iyz="-1.325674e-03" izz="2.870070e-01"/>
    </inertial>
    <visual>
      <origin xyz="0.000000 0.000000 0.000000" rpy="0.000000 0.000000 -2.094395"/>
      <geometry>
        <mesh filename="package://kiwi_drive_description/meshes/base_link/base_link.dae" scale="1 1 1"/>
      </geometry>
      <material name="Steel"/>
    </visual>
    <collision>
      <origin xyz="0.000000 0.000000 0.000000" rpy="0.000000 0.000000 -2.094395"/>
      <geometry>
        <mesh filename="package://kiwi_drive_description/meshes/base_link/base_link_collision.stl" scale="0.01 0.01 0.01"/>
      </geometry>
    </collision>
  </link>

  <link name="wheel_1_link_Omni_Wheel">
    <inertial>
      <origin xyz="-0.000012 0.000023 0.019966" rpy="0 0 0"/>
      <mass value="1.797779"/>
      <inertia ixx="1.321954e-03" ixy="6.572010e-09" ixz="1.235774e-06" iyy="1.321788e-03" iyz="-2.278703e-06" izz="2.173746e-03"/>
    </inertial>
    <visual>
      <origin xyz="-0.088814 0.603225 0.367959" rpy="3.119159 -1.068867 -1.590625"/>
      <geometry>
        <mesh filename="package://kiwi_drive_description/meshes/wheel_1_link/wheel_1_link_Omni_Wheel.dae" scale="1 1 1"/>
      </geometry>
      <material name="Steel"/>
    </visual>
    <collision>
      <origin xyz="-0.088814 0.603225 0.367959" rpy="3.119159 -1.068867 -1.590625"/>
      <geometry>
        <mesh filename="package://kiwi_drive_description/meshes/wheel_1_link/wheel_1_link_Omni_Wheel_collision.stl" scale="0.01 0.01 0.01"/>
      </geometry>
    </collision>
  </link>

  <link name="wheel_2_link_Omni_Wheel">
    <inertial>
      <origin xyz="0.000013 -0.000005 0.019966" rpy="0 0 0"/>
      <mass value="1.797779"/>
      <inertia ixx="1.321942e-03" ixy="3.160562e-08" ixz="-1.330413e-06" iyy="1.321755e-03" iyz="5.539069e-07" izz="2.173771e-03"/>
    </inertial>
    <visual>
      <origin xyz="0.129426 -0.595834 0.367959" rpy="3.119159 -1.068867 1.618682"/>
      <geometry>
        <mesh filename="package://kiwi_drive_description/meshes/wheel_2_link/wheel_2_link_Omni_Wheel.dae" scale="1 1 1"/>
      </geometry>
      <material name="Steel"/>
    </visual>
    <collision>
      <origin xyz="0.129426 -0.595834 0.367959" rpy="3.119159 -1.068867 1.618682"/>
      <geometry>
        <mesh filename="package://kiwi_drive_description/meshes/wheel_2_link/wheel_2_link_Omni_Wheel_collision.stl" scale="0.01 0.01 0.01"/>
      </geometry>
    </collision>
  </link>

  <link name="wheel_3_link_Omni_Wheel">
    <inertial>
      <origin xyz="-0.000014 -0.000026 0.019967" rpy="0 0 0"/>
      <mass value="1.797779"/>
      <inertia ixx="1.321962e-03" ixy="4.465450e-08" ixz="1.418671e-06" iyy="1.321802e-03" iyz="2.397399e-06" izz="2.173733e-03"/>
    </inertial>
    <visual>
      <origin xyz="-0.089816 0.603077 0.367959" rpy="3.119159 -1.068867 -1.588963"/>
      <geometry>
        <mesh filename="package://kiwi_drive_description/meshes/wheel_3_link/wheel_3_link_Omni_Wheel.dae" scale="1 1 1"/>
      </geometry>
      <material name="Steel"/>
    </visual>
    <collision>
      <origin xyz="-0.089816 0.603077 0.367959" rpy="3.119159 -1.068867 -1.588963"/>
      <geometry>
        <mesh filename="package://kiwi_drive_description/meshes/wheel_3_link/wheel_3_link_Omni_Wheel_collision.stl" scale="0.01 0.01 0.01"/>
      </geometry>
    </collision>
  </link>

  <link name="Lidar_Mounting_Plate">
    <inertial>
      <origin xyz="-0.002558 0.020131 0.010134" rpy="0 0 0"/>
      <mass value="1.086176"/>
      <inertia ixx="1.522713e-03" ixy="9.869876e-05" ixz="5.571067e-06" iyy="8.842444e-04" iyz="1.271763e-04" izz="1.946043e-03"/>
    </inertial>
    <visual>
      <origin xyz="0.000000 0.000000 0.000000" rpy="0.000000 0.000000 0.000000"/>
      <geometry>
        <mesh filename="package://kiwi_drive_description/meshes/lidar_link/Lidar_Mounting_Plate.dae" scale="1 1 1"/>
      </geometry>
      <material name="Steel"/>
    </visual>
    <collision>
      <origin xyz="0.000000 0.000000 0.000000" rpy="0.000000 0.000000 0.000000"/>
      <geometry>
        <mesh filename="package://kiwi_drive_description/meshes/lidar_link/Lidar_Mounting_Plate_collision.stl" scale="0.01 0.01 0.01"/>
      </geometry>
    </collision>
  </link>

  <joint name="wheel_1_to_base_link" type="continuous">
    <parent link="base_link"/>
    <child link="wheel_1_link_Omni_Wheel"/>
    <origin xyz="0.269094 -0.155140 -0.028295" rpy="-1.588336 0.031105 1.057255"/>
    <axis xyz="0.000000 0.000000 1.000000"/>
    <limit effort="100.0" velocity="1.00"/>
  </joint>

  <joint name="wheel_2_to_base_link" type="continuous">
    <parent link="base_link"/>
    <child link="wheel_2_link_Omni_Wheel"/>
    <origin xyz="-0.000532 0.310563 -0.028788" rpy="1.574419 -0.000039 0.010768"/>
    <axis xyz="0.000000 0.000000 1.000000"/>
    <limit effort="100.0" velocity="1.00"/>
  </joint>

  <joint name="wheel_3_to_base_link" type="continuous">
    <parent link="base_link"/>
    <child link="wheel_3_link_Omni_Wheel"/>
    <origin xyz="-0.269016 -0.155795 -0.029665" rpy="-1.549628 0.035717 -1.035628"/>
    <axis xyz="0.000000 0.000000 1.000000"/>
    <limit effort="100.0" velocity="1.00"/>
  </joint>

  <joint name="base_link_to_lidar_link" type="fixed">
    <parent link="base_link"/>
    <child link="Lidar_Mounting_Plate"/>
    <origin xyz="-0.000151 -0.115009 0.024945" rpy="0.000000 0.000000 0.000000"/>
  </joint>

  <!-- ROS 2 control: generated generic system -->
  <ros2_control name="Kiwi_Drive_Full_Assembly_Copy_Copy_system" type="system">
    <hardware>
      <plugin>mock_components/GenericSystem</plugin>
      <param name="cmd_topic">sim/Kiwi_Drive_Full_Assembly_Copy_Copy_system/cmd</param>
      <param name="state_topic">sim/Kiwi_Drive_Full_Assembly_Copy_Copy_system/state</param>
    </hardware>

    <joint name="wheel_1_to_base_link">
      <command_interface name="position"/>
      <command_interface name="velocity"/>
      <state_interface name="position">
        <param name="initial_value">0.0</param>
      </state_interface>
      <state_interface name="velocity"/>
      <state_interface name="effort"/>
    </joint>
    <joint name="wheel_2_to_base_link">
      <command_interface name="position"/>
      <command_interface name="velocity"/>
      <state_interface name="position">
        <param name="initial_value">0.0</param>
      </state_interface>
      <state_interface name="velocity"/>
      <state_interface name="effort"/>
    </joint>
    <joint name="wheel_3_to_base_link">
      <command_interface name="position"/>
      <command_interface name="velocity"/>
      <state_interface name="position">
        <param name="initial_value">0.0</param>
      </state_interface>
      <state_interface name="velocity"/>
      <state_interface name="effort"/>
    </joint>
  </ros2_control>

</robot>

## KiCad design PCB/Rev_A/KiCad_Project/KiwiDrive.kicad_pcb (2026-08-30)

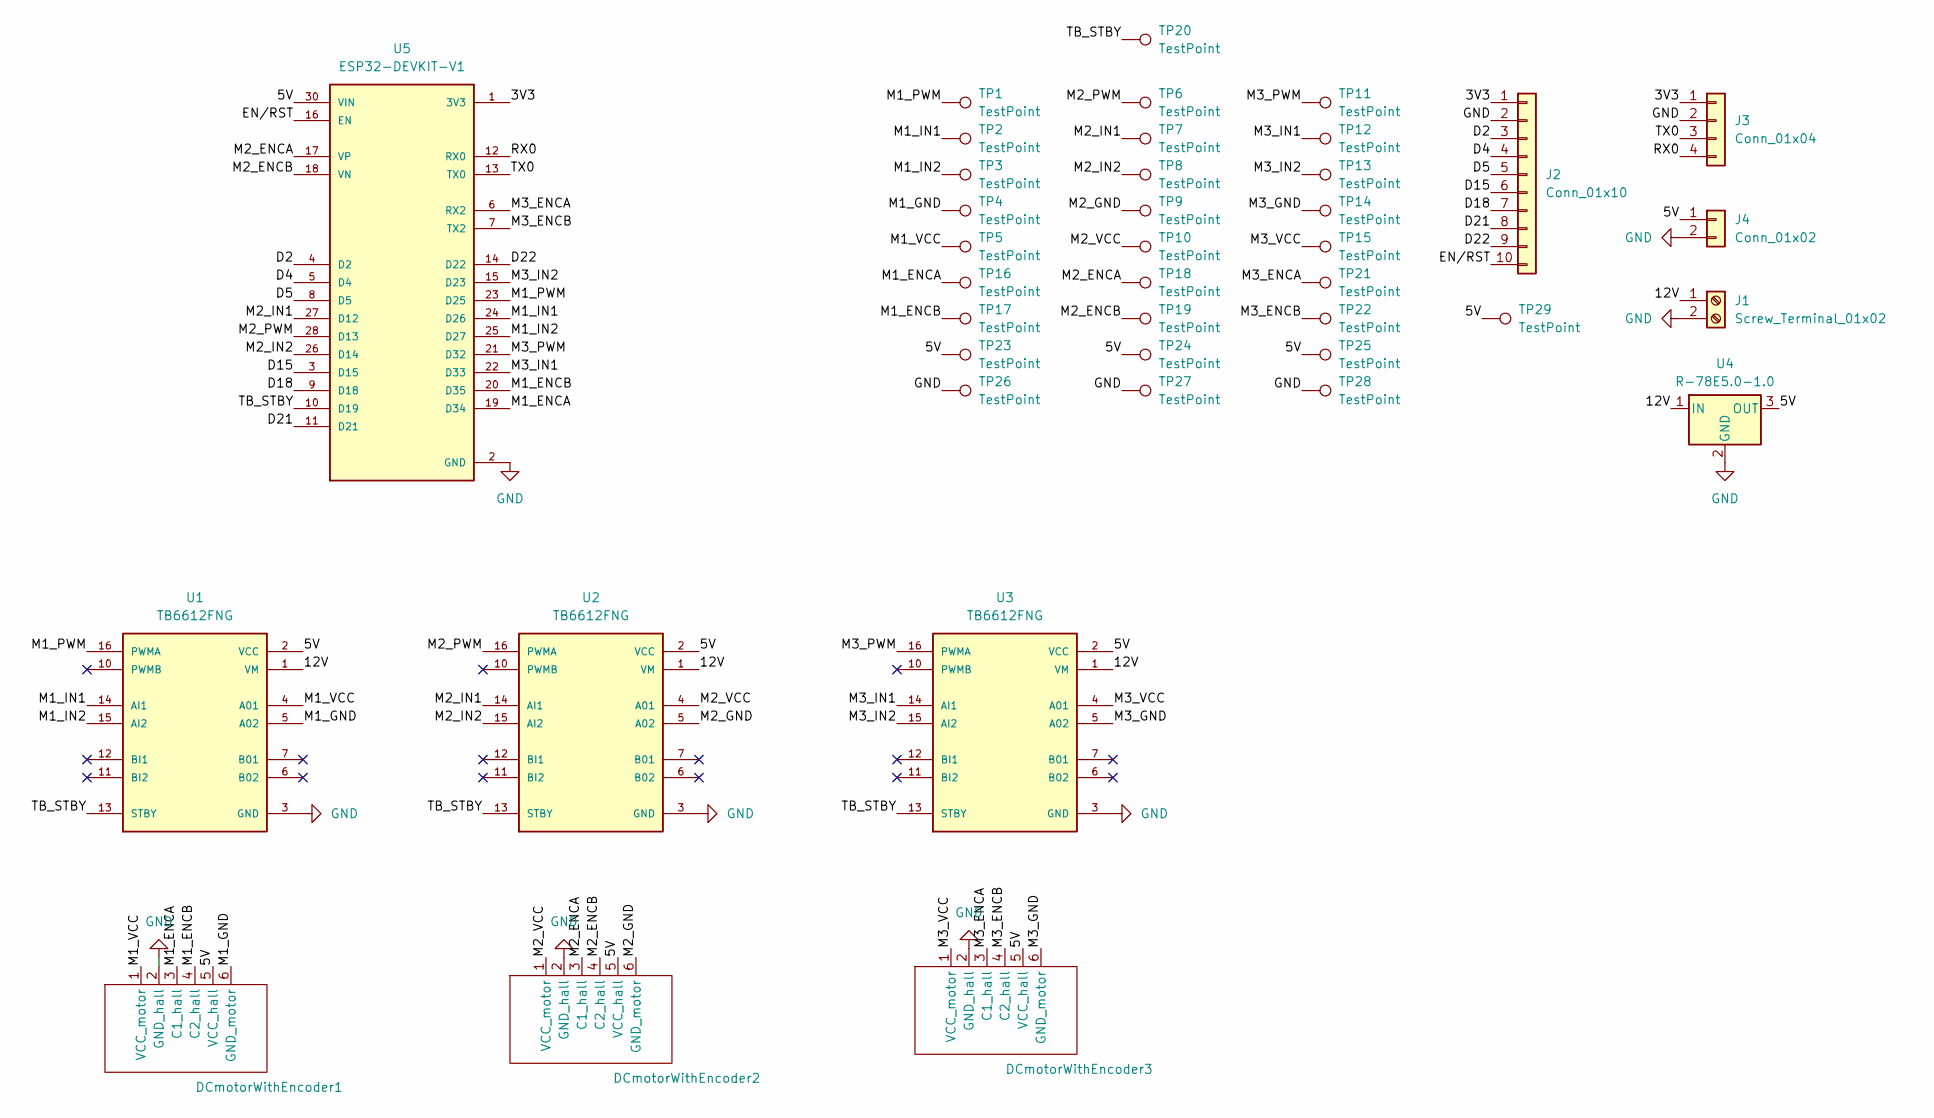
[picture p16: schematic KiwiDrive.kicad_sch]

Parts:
DCmotorWithEncoder1, DCmotorWithEncoder2, DCmotorWithEncoder3: 25GA_Motor_Encoder_6Pin
J1: Screw_Terminal_01x02; AMASS_XT30PW-F_1x02_P2.50mm_Horizontal
J2: Conn_01x10; PinHeader_1x10_P2.54mm_Vertical
J3: Conn_01x04; PinHeader_1x04_P2.54mm_Vertical
J4: Conn_01x02; PinHeader_1x02_P2.54mm_Vertical
TP1, TP2, TP3, TP4, TP5, TP6, TP7, TP8, TP9, TP10, TP11, TP12, TP13, TP14, TP15, TP16, TP17, TP18, TP19, TP20, TP21, TP22, TP23, TP24, TP25, TP26, TP27, TP28, TP29: TestPoint; TestPoint_Pad_1.0x1.0mm
U1, U2, U3: TB6612FNG
U4: R-78E5.0-1.0; Converter_DCDC_RECOM_R-78E-0.5_THT
U5: ESP32-DEVKIT-V1; MODULE_ESP32_DEVKIT_V1; PARTREV N/A

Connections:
/3V3: J2.1, J3.1, U5.1 (3V3)
/5V: DCmotorWithEncoder1.5 (VCC_hall), DCmotorWithEncoder2.5 (VCC_hall), DCmotorWithEncoder3.5 (VCC_hall), J4.1, TP23.1 (1_1), TP24.1 (1_1), TP25.1 (1_1), TP29.1 (1_1), U1.2 (VCC), U2.2 (VCC), U3.2 (VCC), U4.3 (OUT), U5.30 (VIN)
/12V: J1.1, U1.1 (VM), U2.1 (VM), U3.1 (VM), U4.1 (IN)
/D2: J2.3, U5.4 (D2)
/D4: J2.4, U5.5 (D4)
/D5: J2.5, U5.8 (D5)
/D15: J2.6, U5.3 (D15)
/D18: J2.7, U5.9 (D18)
/D21: J2.8, U5.11 (D21)
/D22: J2.9, U5.14 (D22)
/EN/RST: J2.10, U5.16 (EN)
/M1_ENCA: DCmotorWithEncoder1.3 (C1_hall), TP16.1 (1_1), U5.19 (D34)
/M1_ENCB: DCmotorWithEncoder1.4 (C2_hall), TP17.1 (1_1), U5.20 (D35)
/M1_GND: DCmotorWithEncoder1.6 (GND_motor), TP4.1 (1_1), U1.5 (A02)
/M1_IN1: TP2.1 (1_1), U1.14 (AI1), U5.24 (D26)
/M1_IN2: TP3.1 (1_1), U1.15 (AI2), U5.25 (D27)
/M1_PWM: TP1.1 (1_1), U1.16 (PWMA), U5.23 (D25)
/M1_VCC: DCmotorWithEncoder1.1 (VCC_motor), TP5.1 (1_1), U1.4 (A01)
/M2_ENCA: DCmotorWithEncoder2.3 (C1_hall), TP18.1 (1_1), U5.17 (VP)
/M2_ENCB: DCmotorWithEncoder2.4 (C2_hall), TP19.1 (1_1), U5.18 (VN)
/M2_GND: DCmotorWithEncoder2.6 (GND_motor), TP9.1 (1_1), U2.5 (A02)
/M2_IN1: TP7.1 (1_1), U2.14 (AI1), U5.27 (D12)
/M2_IN2: TP8.1 (1_1), U2.15 (AI2), U5.26 (D14)
/M2_PWM: TP6.1 (1_1), U2.16 (PWMA), U5.28 (D13)
/M2_VCC: DCmotorWithEncoder2.1 (VCC_motor), TP10.1 (1_1), U2.4 (A01)
/M3_ENCA: DCmotorWithEncoder3.3 (C1_hall), TP21.1 (1_1), U5.6 (RX2)
/M3_ENCB: DCmotorWithEncoder3.4 (C2_hall), TP22.1 (1_1), U5.7 (TX2)
/M3_GND: DCmotorWithEncoder3.6 (GND_motor), TP14.1 (1_1), U3.5 (A02)
/M3_IN1: TP12.1 (1_1), U3.14 (AI1), U5.22 (D33)
/M3_IN2: TP13.1 (1_1), U3.15 (AI2), U5.15 (D23)
/M3_PWM: TP11.1 (1_1), U3.16 (PWMA), U5.21 (D32)
/M3_VCC: DCmotorWithEncoder3.1 (VCC_motor), TP15.1 (1_1), U3.4 (A01)
/RX0: J3.4, U5.12 (RX0)
/TB_STBY: TP20.1 (1_1), U1.13 (STBY), U2.13 (STBY), U3.13 (STBY), U5.10 (D19)
/TX0: J3.3, U5.13 (TX0)
GND: DCmotorWithEncoder1.2 (GND_hall), DCmotorWithEncoder2.2 (GND_hall), DCmotorWithEncoder3.2 (GND_hall), J1.2, J2.2, J3.2, J4.2, TP26.1 (1_1), TP27.1 (1_1), TP28.1 (1_1), U1.3 (GND), U1.8 (GND), U1.9 (GND), U2.3 (GND), U2.8 (GND), U2.9 (GND), U3.3 (GND), U3.8 (GND), U3.9 (GND), U4.2 (GND), U5.2 (GND), U5.29 (GND)

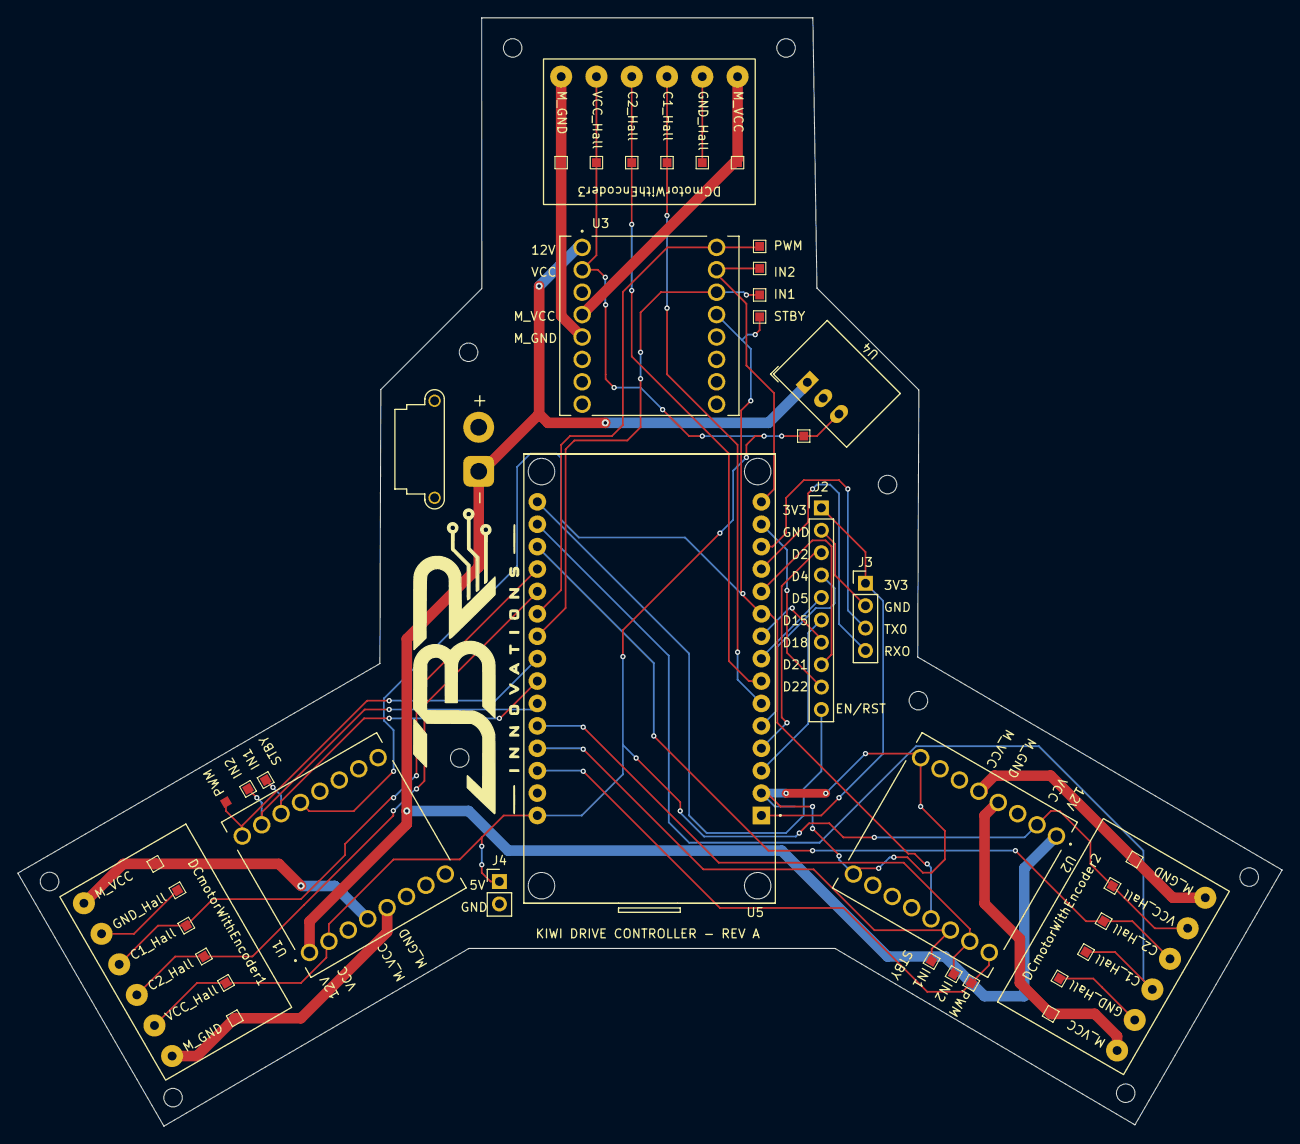
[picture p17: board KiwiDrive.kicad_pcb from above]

Board: 2 copper layers, 143.3 x 125.6 mm, 41 parts (0 on the bottom side), 36 nets.

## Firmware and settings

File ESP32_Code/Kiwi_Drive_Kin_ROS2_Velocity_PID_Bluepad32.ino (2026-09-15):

#include <Bluepad32.h>
#include <esp_arduino_version.h>
#include <math.h>



// ---------------------------------------------------------------------------------------------------------------------------
// Bluepad32 controllers
// ---------------------------------------------------------------------------------------------------------------------------

ControllerPtr myControllers[BP32_MAX_GAMEPADS];





// ---------------------------------------------------------------------------------------------------------------------------
// ESP32 pin assignments
// ---------------------------------------------------------------------------------------------------------------------------

// Shared TB6612FNG standby pin
const uint8_t STBY = 19;

// ---------------- Motor 1 ----------------
const uint8_t M1_PWM = 25;
const uint8_t M1_IN1 = 26;
const uint8_t M1_IN2 = 27;
    //------------- Motor 1 Encoder --------
const uint8_t M1_ENCA = 34;
const uint8_t M1_ENCB = 35;

// ---------------- Motor 2 ----------------
const uint8_t M2_PWM = 13;
const uint8_t M2_IN1 = 12;
const uint8_t M2_IN2 = 14;

    //------------- Motor 1 Encoder --------
    // VP = GPIO36
    // VN = GPIO39
const uint8_t M2_ENCA = 36;
const uint8_t M2_ENCB = 39;

// ---------------- Motor 3 ----------------

const uint8_t M3_PWM = 32;
const uint8_t M3_IN1 = 33;
const uint8_t M3_IN2 = 23;

    //------------- Motor 1 Encoder --------
    // RX2 = GPIO16
    // TX2 = GPIO17
const uint8_t M3_ENCA = 16;
const uint8_t M3_ENCB = 17;





// ---------------------------------------------------------------------------------------------------------------------------
// PWM configuration
// ---------------------------------------------------------------------------------------------------------------------------

const uint32_t PWM_FREQUENCY_HZ = 20000;
const uint8_t PWM_RESOLUTION_BITS = 8;

// Used by ESP32 Arduino Core 2.x
const uint8_t M1_PWM_CHANNEL = 0;
const uint8_t M2_PWM_CHANNEL = 1;
const uint8_t M3_PWM_CHANNEL = 2;





// ---------------------------------------------------------------------------------------------------------------------------
// Controller configuration
// ---------------------------------------------------------------------------------------------------------------------------

// Bluepad32 joystick values are approximately -512 to +512.
const int AXIS_MAX = 512;

const int LEFT_STICK_DEADZONE = 80;
const int RIGHT_STICK_DEADZONE = 30;

// Maximum PWM the speed controller may command.
const int MAX_PWM = 240;

// Smallest PWM that reliably moves the motors.
const int MIN_PWM = 0;

// Overall joystick sensitivity.
const float TRANSLATION_SCALE = 1.00f;
const float ROTATION_SCALE = 0.80f;

// Positive logical wheel command to physical motor direction.
const int M1_DIRECTION = 1;
const int M2_DIRECTION = 1;
const int M3_DIRECTION = 1;

// Serial diagnostic interval. (Set to 100ms so it wont spam the serial).
const unsigned long PRINT_INTERVAL_MS = 100;
unsigned long lastPrintTime = 0;





// ---------------------------------------------------------------------------------------------------------------------------
// Encoder and velocity-control configuration
// ---------------------------------------------------------------------------------------------------------------------------

// Confirmed using full x4 quadrature decoding.
const float COUNTS_PER_REVOLUTION = 1976.1f;

// ROS / odometry telemetry interval (20 Hz or ever 50ms).
const unsigned long ODOM_TELEMETRY_INTERVAL_MS = 50;
unsigned long lastOdomTelemetryTime = 0;

// Leave control headroom below the nominal 130 RPM no-load speed.
// (after watching video this is important for autonomous control because it leaves headroom to allow the robot to speed up if detecting an error if needed to).
const float MAX_TARGET_RPM = 120.0f;

// Velocity loop at 50 Hz. (20ms) (50x per sec).
const uint32_t PID_PERIOD_US = 20000;

// Positive motor command produced negative raw encoder counts in
// the Motor 3 position test. Since all three encoders are wired
// identically I simply inverted all 3 for ideal operation.
const int ENCODER_DIRECTION[3] = {-1, -1, -1};

// Starting PID gains.
float velocityKp[3] = {0.80f, 0.80f, 0.80f};
float velocityKi[3] = {0.30f, 0.30f, 0.30f};
float velocityKd[3] = {0.05f, 0.05f, 0.05f};

// RPM first order low-pass filter: 0 = no new data, 1 = no filtering. ( RPMfilt = alpha * RPMnew + (1 - alpha)RPMold )
const float RPM_FILTER_ALPHA = 0.30f;

// Stop tiny target commands.
const float TARGET_RPM_DEADBAND = 1.0f;

// Integral anti-windup limit. (I == I + e * delta_t) this is very important for making if a wheel is stuck
// and commands to that wheel want a specific rpm this will prevent the error integral from shooting up (limits to -100 <-> 100)
const float INTEGRAL_LIMIT = 100.0f;





// ---------------------------------------------------------------------------------------------------------------------------
// Manual / autonomous mode configuration
// ---------------------------------------------------------------------------------------------------------------------------


// Manual is for using the bluetooth controller (xbox) and autonomous is for ROS2 and Nav2 control thru the pi
enum class ControlMode {
  MANUAL,
  AUTONOMOUS
};

// Starts the controller in manual, will update to autonomous if wanting to start off in self nav
ControlMode controlMode = ControlMode::MANUAL;

// Xbox Start button misc bit.
const uint8_t START_MISC_MASK = 0x04;

// Stop the robot if the Pi stops refreshing autonomous commands. So if ROS2 crashes which did happen a couple times this will stop
// the robot rather than continuing indefinetly 
const unsigned long AUTO_COMMAND_TIMEOUT_MS = 300;

String serialCommandBuffer;
unsigned long lastAutoCommandTimeMs = 0; // storing the last autonomous command
bool autoTimeoutActive = false;          // if timeout occurs this will flip so rather than repeating the timeout error indefinetly it does it once
bool startButtonWasPressed = false;      





// ---------------------------------------------------------------------------------------------------------------------------
// Runtime state
// ---------------------------------------------------------------------------------------------------------------------------

//  actual pwm output calculated by controller (not the targeted RPM or measured RPM)
int motor1Command = 0;
int motor2Command = 0;
int motor3Command = 0;

//  Linked this to A so pressing A will cause the software motor switch, to switch back pressing B can be pressed
bool emergencyStopActive = false;

// Encoder state.
volatile int32_t encoderCount[3] = {0, 0, 0};
volatile uint8_t previousEncoderState[3] = {0, 0, 0};

// Quadrature lookup table in RAM for ISR use.
DRAM_ATTR const int8_t QUADRATURE_TABLE[16] = {
   0, -1,  1,  0,
   1,  0,  0, -1,
  -1,  0,  0,  1,
   0,  1, -1,  0
};

portMUX_TYPE encoderMux = portMUX_INITIALIZER_UNLOCKED;

// Velocity controller state.
int32_t previousPIDEncoderCount[3] = {0, 0, 0};

float targetRPM[3] = {0.0f, 0.0f, 0.0f};
float measuredRPM[3] = {0.0f, 0.0f, 0.0f};
float rawRPM[3] = {0.0f, 0.0f, 0.0f};

float velocityIntegral[3] = {0.0f, 0.0f, 0.0f};
float previousVelocityError[3] = {0.0f, 0.0f, 0.0f};

uint32_t previousPIDTimeUs = 0;





// ---------------------------------------------------------------------------------------------------------------------------
// Function declarations
// ---------------------------------------------------------------------------------------------------------------------------

void stopAllMotors();
void enableMotorDrivers();
void disableMotorDrivers();

void configurePWM();
void writeMotorPWM(uint8_t pwmPin, uint8_t channel, int duty);

void setMotor(
  uint8_t pwmPin,
  uint8_t pwmChannel,
  uint8_t in1Pin,
  uint8_t in2Pin,
  int speed
);

void resetVelocityController();
void driveKiwi(float x, float y, float rotation);
void runVelocityPID();

void processSerialCommands();
void processCompleteSerialCommand(String command);
void setControlMode(ControlMode newMode, const char* source);
void checkAutonomousTimeout();
const char* controlModeName();

void processControllers();
void processGamepad(ControllerPtr ctl);
void printControllerData(
  ControllerPtr ctl,
  int rawLX,
  int rawLY,
  int rawRX,
  float x,
  float y,
  float rotation
);

void sendOdometryTelemetry();

void IRAM_ATTR motor1EncoderISR();
void IRAM_ATTR motor2EncoderISR();
void IRAM_ATTR motor3EncoderISR();





// ---------------------------------------------------------------------------------------------------------------------------
// Bluepad32 callbacks
// ---------------------------------------------------------------------------------------------------------------------------

void onConnectedController(ControllerPtr ctl) {
  for (int i = 0; i < BP32_MAX_GAMEPADS; i++) {
    if (myControllers[i] == nullptr) {
      myControllers[i] = ctl;

      ControllerProperties properties = ctl->getProperties();

      Serial.println();
      Serial.println("=================================");
      Serial.printf("CONTROLLER CONNECTED: slot %d\n", i);
      Serial.printf("Model: %s\n", ctl->getModelName().c_str());
      Serial.printf(
        "VID: 0x%04X  PID: 0x%04X\n",
        properties.vendor_id,
        properties.product_id
      );
      Serial.println("=================================");

      emergencyStopActive = false;
      stopAllMotors();
      enableMotorDrivers();
      return;
    }
  }

  Serial.println(
    "Controller connected, but no controller slot was available."
  );
}

void onDisconnectedController(ControllerPtr ctl) {
  for (int i = 0; i < BP32_MAX_GAMEPADS; i++) {
    if (myControllers[i] == ctl) {
      myControllers[i] = nullptr;

      Serial.println();
      Serial.printf(
        "CONTROLLER DISCONNECTED: slot %d\n",
        i
      );

      startButtonWasPressed = false;
      stopAllMotors();
      disableMotorDrivers();
      return;
    }
  }
}





// ---------------------------------------------------------------------------------------------------------------------------
// PWM functions
// ---------------------------------------------------------------------------------------------------------------------------

void configurePWM() {
#if ESP_ARDUINO_VERSION_MAJOR >= 3

  bool motor1Attached = ledcAttach(
    M1_PWM,
    PWM_FREQUENCY_HZ,
    PWM_RESOLUTION_BITS
  );

  bool motor2Attached = ledcAttach(
    M2_PWM,
    PWM_FREQUENCY_HZ,
    PWM_RESOLUTION_BITS
  );

  bool motor3Attached = ledcAttach(
    M3_PWM,
    PWM_FREQUENCY_HZ,
    PWM_RESOLUTION_BITS
  );

#else

  ledcSetup(
    M1_PWM_CHANNEL,
    PWM_FREQUENCY_HZ,
    PWM_RESOLUTION_BITS
  );

  ledcSetup(
    M2_PWM_CHANNEL,
    PWM_FREQUENCY_HZ,
    PWM_RESOLUTION_BITS
  );

  ledcSetup(
    M3_PWM_CHANNEL,
    PWM_FREQUENCY_HZ,
    PWM_RESOLUTION_BITS
  );

  ledcAttachPin(M1_PWM, M1_PWM_CHANNEL);
  ledcAttachPin(M2_PWM, M2_PWM_CHANNEL);
  ledcAttachPin(M3_PWM, M3_PWM_CHANNEL);

  bool motor1Attached = true;
  bool motor2Attached = true;
  bool motor3Attached = true;

#endif

  if (!motor1Attached ||
      !motor2Attached ||
      !motor3Attached) {
    Serial.println(
      "ERROR: One or more PWM pins failed to attach."
    );
  } else {
    Serial.printf(
      "PWM configured: %lu Hz, %u-bit\n",
      PWM_FREQUENCY_HZ,
      PWM_RESOLUTION_BITS
    );
  }
}

void writeMotorPWM(
  uint8_t pwmPin,
  uint8_t channel,
  int duty
) {
  duty = constrain(duty, 0, 255);

#if ESP_ARDUINO_VERSION_MAJOR >= 3
  ledcWrite(pwmPin, duty);
#else
  ledcWrite(channel, duty);
#endif
}





// ---------------------------------------------------------------------------------------------------------------------------
// Motor-driver control
// ---------------------------------------------------------------------------------------------------------------------------

void enableMotorDrivers() {
  digitalWrite(STBY, HIGH);
}

void disableMotorDrivers() {
  digitalWrite(STBY, LOW);
}

void setMotor(
  uint8_t pwmPin,
  uint8_t pwmChannel,
  uint8_t in1Pin,
  uint8_t in2Pin,
  int speed
) {
  speed = constrain(speed, -255, 255);

  if (speed > 0) {
    digitalWrite(in1Pin, HIGH);
    digitalWrite(in2Pin, LOW);
    writeMotorPWM(pwmPin, pwmChannel, speed);
  } else if (speed < 0) {
    digitalWrite(in1Pin, LOW);
    digitalWrite(in2Pin, HIGH);
    writeMotorPWM(pwmPin, pwmChannel, -speed);
  } else {
    writeMotorPWM(pwmPin, pwmChannel, 0);

    // Coast mode.
    digitalWrite(in1Pin, LOW);
    digitalWrite(in2Pin, LOW);
  }
}

void resetVelocityController() {
  portENTER_CRITICAL(&encoderMux);
  previousPIDEncoderCount[0] = encoderCount[0];
  previousPIDEncoderCount[1] = encoderCount[1];
  previousPIDEncoderCount[2] = encoderCount[2];
  portEXIT_CRITICAL(&encoderMux);

  for (int i = 0; i < 3; i++) {
    targetRPM[i] = 0.0f;
    rawRPM[i] = 0.0f;
    measuredRPM[i] = 0.0f;
    velocityIntegral[i] = 0.0f;
    previousVelocityError[i] = 0.0f;
  }

  previousPIDTimeUs = micros();
}

void stopAllMotors() {
  targetRPM[0] = 0.0f;
  targetRPM[1] = 0.0f;
  targetRPM[2] = 0.0f;

  velocityIntegral[0] = 0.0f;
  velocityIntegral[1] = 0.0f;
  velocityIntegral[2] = 0.0f;

  previousVelocityError[0] = 0.0f;
  previousVelocityError[1] = 0.0f;
  previousVelocityError[2] = 0.0f;

  motor1Command = 0;
  motor2Command = 0;
  motor3Command = 0;

  setMotor(
    M1_PWM,
    M1_PWM_CHANNEL,
    M1_IN1,
    M1_IN2,
    0
  );

  setMotor(
    M2_PWM,
    M2_PWM_CHANNEL,
    M2_IN1,
    M2_IN2,
    0
  );

  setMotor(
    M3_PWM,
    M3_PWM_CHANNEL,
    M3_IN1,
    M3_IN2,
    0
  );
}





// ---------------------------------------------------------------------------------------------------------------------------
// Encoder interrupts
// ---------------------------------------------------------------------------------------------------------------------------

void IRAM_ATTR updateEncoderFromISR(
  uint8_t motorIndex,
  uint8_t pinA,
  uint8_t pinB
) {
  const uint8_t a = digitalRead(pinA);
  const uint8_t b = digitalRead(pinB);
  const uint8_t currentState = (a << 1) | b;

  portENTER_CRITICAL_ISR(&encoderMux);

  const uint8_t tableIndex =
    (previousEncoderState[motorIndex] << 2) |
    currentState;

  encoderCount[motorIndex] +=
    ENCODER_DIRECTION[motorIndex] *
    QUADRATURE_TABLE[tableIndex];

  previousEncoderState[motorIndex] = currentState;

  portEXIT_CRITICAL_ISR(&encoderMux);
}

void IRAM_ATTR motor1EncoderISR() {
  updateEncoderFromISR(0, M1_ENCA, M1_ENCB);
}

void IRAM_ATTR motor2EncoderISR() {
  updateEncoderFromISR(1, M2_ENCA, M2_ENCB);
}

void IRAM_ATTR motor3EncoderISR() {
  updateEncoderFromISR(2, M3_ENCA, M3_ENCB);
}





// ---------------------------------------------------------------------------------------------------------------------------
// Input-processing functions
// ---------------------------------------------------------------------------------------------------------------------------

float normalizeAxisWithDeadzone(
  int rawValue,
  int deadzone
) {
  int magnitude = abs(rawValue);

  if (magnitude <= deadzone) {
    return 0.0f;
  }

  float normalizedMagnitude =
    static_cast<float>(magnitude - deadzone) /
    static_cast<float>(AXIS_MAX - deadzone);

  normalizedMagnitude = constrain(
    normalizedMagnitude,
    0.0f,
    1.0f
  );

  return rawValue < 0
           ? -normalizedMagnitude
           : normalizedMagnitude;
}





// ---------------------------------------------------------------------------------------------------------------------------
// Kiwi-drive calculations
// ---------------------------------------------------------------------------------------------------------------------------

void driveKiwi(
  float x,
  float y,
  float rotation
) {
  const float SIN_60 = 0.8660254f;

  x *= TRANSLATION_SCALE;
  y *= TRANSLATION_SCALE;
  rotation *= ROTATION_SCALE;

  /*
            FRONT OF ROBOT
                ^

        Motor 1       Motor 3
             \         /
              \       /
                Motor 2

                  BACK

    x: positive = robot right
    y: positive = robot forward
  */

  float wheel1 =
    (-0.5f * x) +
    (SIN_60 * y) +
    rotation;

  float wheel2 =
      x +
      rotation;

  float wheel3 =
      (-0.5f * x) -
      (SIN_60 * y) +
      rotation;

  // Preserve wheel ratios while limiting every command to +/-1.
  float largest = fabsf(wheel1);

  if (fabsf(wheel2) > largest) {
    largest = fabsf(wheel2);
  }

  if (fabsf(wheel3) > largest) {
    largest = fabsf(wheel3);
  }

  if (largest > 1.0f) {
    wheel1 /= largest;
    wheel2 /= largest;
    wheel3 /= largest;
  }

  // Create target RPM instead of direct PWM.
  targetRPM[0] =
    wheel1 * MAX_TARGET_RPM * M1_DIRECTION;

  targetRPM[1] =
    wheel2 * MAX_TARGET_RPM * M2_DIRECTION;

  targetRPM[2] =
    wheel3 * MAX_TARGET_RPM * M3_DIRECTION;

  for (int i = 0; i < 3; i++) {
    if (fabsf(targetRPM[i]) < TARGET_RPM_DEADBAND) {
      targetRPM[i] = 0.0f;
    }
  }
}





// ---------------------------------------------------------------------------------------------------------------------------
// Velocity PID
// ---------------------------------------------------------------------------------------------------------------------------

void applyMotorCommand(uint8_t motorIndex, int command) {
  switch (motorIndex) {
    case 0:
      motor1Command = command;
      setMotor(
        M1_PWM,
        M1_PWM_CHANNEL,
        M1_IN1,
        M1_IN2,
        motor1Command
      );
      break;

    case 1:
      motor2Command = command;
      setMotor(
        M2_PWM,
        M2_PWM_CHANNEL,
        M2_IN1,
        M2_IN2,
        motor2Command
      );
      break;

    case 2:
      motor3Command = command;
      setMotor(
        M3_PWM,
        M3_PWM_CHANNEL,
        M3_IN1,
        M3_IN2,
        motor3Command
      );
      break;
  }
}

void runVelocityPID() {
  const uint32_t currentTimeUs = micros();

  if (
    static_cast<uint32_t>(
      currentTimeUs - previousPIDTimeUs
    ) < PID_PERIOD_US
  ) {
    return;
  }

  const float dt =
    static_cast<float>(
      static_cast<uint32_t>(
        currentTimeUs - previousPIDTimeUs
      )
    ) / 1000000.0f;

  previousPIDTimeUs = currentTimeUs;

  // Reject unreasonable timing intervals.
  if (dt <= 0.0f || dt > 0.25f) {
    resetVelocityController();
    return;
  }

  int32_t currentCounts[3];

  portENTER_CRITICAL(&encoderMux);
  currentCounts[0] = encoderCount[0];
  currentCounts[1] = encoderCount[1];
  currentCounts[2] = encoderCount[2];
  portEXIT_CRITICAL(&encoderMux);

  for (uint8_t i = 0; i < 3; i++) {
    const int32_t deltaCounts =
      currentCounts[i] -
      previousPIDEncoderCount[i];

    previousPIDEncoderCount[i] =
      currentCounts[i];

    rawRPM[i] =
      (
        static_cast<float>(deltaCounts) /
        COUNTS_PER_REVOLUTION
      ) *
      (60.0f / dt);

    measuredRPM[i] =
      RPM_FILTER_ALPHA * rawRPM[i] +
      (1.0f - RPM_FILTER_ALPHA) * measuredRPM[i];

    if (
      emergencyStopActive ||
      fabsf(targetRPM[i]) <
        TARGET_RPM_DEADBAND
    ) {
      velocityIntegral[i] = 0.0f;
      previousVelocityError[i] = 0.0f;
      applyMotorCommand(i, 0);
      continue;
    }

    const float error =
      targetRPM[i] - measuredRPM[i];

    velocityIntegral[i] += error * dt;

    velocityIntegral[i] = constrain(
      velocityIntegral[i],
      -INTEGRAL_LIMIT,
      INTEGRAL_LIMIT
    );

    const float derivative =
      (error - previousVelocityError[i]) / dt;

    previousVelocityError[i] = error;

    /*
      Feed-forward supplies most of the expected PWM.
      PID corrects motor mismatch, load, friction, and
      battery-voltage changes.
    */
    const float feedForward =
      (targetRPM[i] / MAX_TARGET_RPM) *
      static_cast<float>(MAX_PWM);

    const float correction =
      velocityKp[i] * error +
      velocityKi[i] * velocityIntegral[i] +
      velocityKd[i] * derivative;

    float pwmOutput =
      feedForward + correction;

    pwmOutput = constrain(
      pwmOutput,
      -static_cast<float>(MAX_PWM),
      static_cast<float>(MAX_PWM)
    );

    // Overcome static friction without changing direction.
    if (
      pwmOutput > 0.0f &&
      pwmOutput < static_cast<float>(MIN_PWM)
    ) {
      pwmOutput = static_cast<float>(MIN_PWM);
    } else if (
      pwmOutput < 0.0f &&
      pwmOutput > -static_cast<float>(MIN_PWM)
    ) {
      pwmOutput = -static_cast<float>(MIN_PWM);
    }

    applyMotorCommand(
      i,
      static_cast<int>(roundf(pwmOutput))
    );
  }
}





// ---------------------------------------------------------------------------------------------------------------------------
// Manual / autonomous mode and serial commands
// ---------------------------------------------------------------------------------------------------------------------------

const char* controlModeName() {
  return controlMode == ControlMode::MANUAL
           ? "MANUAL"
           : "AUTO";
}

void setControlMode(
  ControlMode newMode,
  const char* source
) {
  if (controlMode == newMode) {
    return;
  }

  stopAllMotors();
  resetVelocityController();

  controlMode = newMode;
  autoTimeoutActive = false;

  if (
    controlMode == ControlMode::AUTONOMOUS
  ) {
    lastAutoCommandTimeMs = millis();
  }

  if (!emergencyStopActive) {
    enableMotorDrivers();
  }

  Serial.printf(
    "MODE,%s,SOURCE,%s\n",
    controlModeName(),
    source
  );
}
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
void loop() {
  BP32.update();

  // USB commands from Raspberry Pi / ROS 2.
  processSerialCommands();

  // Keep controller buttons active in both modes.
  processControllers();

  // Safety watchdog for AUTO mode.
  checkAutonomousTimeout();

  // Per-wheel velocity PID at 50 Hz.
  runVelocityPID();

  // Send wheel RPM + encoder counts for ROS odometry.
  sendOdometryTelemetry();

  delay(1);
}

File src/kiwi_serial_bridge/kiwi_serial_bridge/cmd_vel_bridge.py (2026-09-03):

#!/usr/bin/env python3

import math
import threading
import time

import rclpy
from geometry_msgs.msg import TransformStamped, TwistStamped
from nav_msgs.msg import Odometry
from rclpy.node import Node
import serial
from serial import SerialException
from tf2_ros import TransformBroadcaster


class CmdVelSerialBridge(Node):
    """Send velocity commands to the ESP32 and publish wheel odometry."""

    def __init__(self) -> None:
        super().__init__("cmd_vel_serial_bridge")

        # ==================================================
        # ROS parameters
        # ==================================================

        self.declare_parameter("serial_port", "/dev/ttyUSB0")
        self.declare_parameter("baud_rate", 115200)

        self.declare_parameter("max_linear_speed", 0.30)
        self.declare_parameter("max_angular_speed", 1.00)

        # Permanent robot geometry.
        self.declare_parameter("wheel_radius", 0.050)
        self.declare_parameter("wheel_distance", 0.2921)

        self.declare_parameter("command_rate_hz", 20.0)
        self.declare_parameter("ros_command_timeout", 0.25)

        self.declare_parameter("odom_frame", "odom")
        self.declare_parameter("base_frame", "base_link")

        # Permanent direction corrections.
        self.declare_parameter("odom_y_direction", -1.0)
        self.declare_parameter("odom_yaw_direction", 1.0)

        # ==================================================
        # Read parameters
        # ==================================================

        self.serial_port = (
            self.get_parameter("serial_port")
            .get_parameter_value()
            .string_value
        )

        self.baud_rate = (
            self.get_parameter("baud_rate")
            .get_parameter_value()
            .integer_value
        )

        self.max_linear_speed = (
            self.get_parameter("max_linear_speed")
            .get_parameter_value()
            .double_value
        )

        self.max_angular_speed = (
            self.get_parameter("max_angular_speed")
            .get_parameter_value()
            .double_value
        )

        self.wheel_radius = (
            self.get_parameter("wheel_radius")
            .get_parameter_value()
            .double_value
        )

        self.wheel_distance = (
            self.get_parameter("wheel_distance")
            .get_parameter_value()
            .double_value
        )

        self.command_rate_hz = (
            self.get_parameter("command_rate_hz")
            .get_parameter_value()
            .double_value
        )

        self.ros_command_timeout = (
            self.get_parameter("ros_command_timeout")
            .get_parameter_value()
            .double_value
        )

        self.odom_frame = (
            self.get_parameter("odom_frame")
            .get_parameter_value()
            .string_value
        )

        self.base_frame = (
            self.get_parameter("base_frame")
            .get_parameter_value()
            .string_value
        )

        self.odom_y_direction = (
            self.get_parameter("odom_y_direction")
            .get_parameter_value()
            .double_value
        )

        self.odom_yaw_direction = (
            self.get_parameter("odom_yaw_direction")
            .get_parameter_value()
            .double_value
        )

        # ==================================================
        # Validate parameters
        # ==================================================

        if self.max_linear_speed <= 0.0:
            raise ValueError("max_linear_speed must be greater than zero")

        if self.max_angular_speed <= 0.0:
            raise ValueError("max_angular_speed must be greater than zero")

        if self.wheel_radius <= 0.0:
            raise ValueError("wheel_radius must be greater than zero")

        if self.wheel_distance <= 0.0:
            raise ValueError("wheel_distance must be greater than zero")

        if self.command_rate_hz <= 0.0:
            raise ValueError("command_rate_hz must be greater than zero")

        # ==================================================
        # Serial connection
        # ==================================================

        try:
            self.serial_connection = serial.Serial(
                port=self.serial_port,
                baudrate=self.baud_rate,
                timeout=0.02,
                write_timeout=0.1,
                xonxoff=False,
                rtscts=False,
                dsrdtr=False,
            )

        except SerialException as error:
            self.get_logger().fatal(
                f"Could not open {self.serial_port}: {error}"
            )
            raise

        time.sleep(2.0)

        self.serial_connection.reset_input_buffer()
        self.serial_connection.reset_output_buffer()

        self.serial_lock = threading.Lock()

        # ==================================================
        # Velocity-command state
        # ==================================================

        self.latest_x = 0.0
        self.latest_y = 0.0
        self.latest_rotation = 0.0

        self.last_cmd_vel_time = self.get_clock().now()

        # ==================================================
        # Odometry state
        # ==================================================

        self.odom_x = 0.0
        self.odom_y = 0.0
        self.odom_yaw = 0.0

        self.last_odom_time = None
        self.odom_packet_count = 0

        # ==================================================
        # ROS interfaces
        # ==================================================

        self.cmd_vel_subscription = self.create_subscription(
            TwistStamped,
            "/cmd_vel",
            self.cmd_vel_callback,
            10,
        )

        self.odom_publisher = self.create_publisher(
            Odometry,
            "/odom",
            20,
        )

        self.tf_broadcaster = TransformBroadcaster(self)

        self.command_timer = self.create_timer(
            1.0 / self.command_rate_hz,
            self.send_latest_command,
        )

        self.serial_read_timer = self.create_timer(
            0.01,
            self.read_serial,
        )

        self.send_line("MODE,AUTO")

        self.get_logger().info(
            f"Connected to ESP32 on {self.serial_port} "
            f"at {self.baud_rate} baud"
        )

        self.get_logger().info(
            "Kiwi geometry: "
            f"wheel radius={self.wheel_radius:.4f} m, "
            f"center-to-wheel={self.wheel_distance:.4f} m"
        )

    # ======================================================
    # Utility functions
    # ======================================================

    @staticmethod
    def clamp(value: float) -> float:
        return max(-1.0, min(value, 1.0))
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

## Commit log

2026-08-29 Backup custom LiDAR and SLAM modifications
2026-08-29 Add README.md for CAD files
2026-08-29 Add initial README for ESP32 Kiwi Drive Code
2026-08-30 Adjust left joystick deadzone, Increased max speed, adjusted PID Kd parameters and fixed kinematics to drive on two front wheels with one rear instead of the reverse.
    [Kiwi_Drive_Kin_ROS2_Velocity_PID_Bluepad32.ino]
2026-08-30 Increase MAX_TARGET_RPM from 100 to 120
    Forgot to do it in the commit before it accompanies raising the max pwm to increase the wheel speed by allowing a higher rpm value
2026-08-30 Add CAD models
    [2020_400mm_Aluminum_Extrusion.step, 2020_Aluminum_Extrusion_Mounting_Spacer.f3d, 2020_Aluminum_Extrusion_Mounting_Spacer.step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]
2026-08-30 Add organized CAD models
    [PCB_Mounting_Enclosure.f3d, PCB_Mounting_Enclosure.step, PCB_Mounting_Enclosure.stl]
2026-08-30 Add README for KiCad PCB and fabrication files
2026-08-30 Add PCB design files and fabrication outputs
    [KiwiDrive-B_Cu.gbr, KiwiDrive-B_Mask.gbr, KiwiDrive-B_Paste.gbr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]
2026-08-30 Add logo footprint library
2026-08-30 Make Gerber output path portable
    [KiwiDrive.kicad_pcb]
2026-08-30 Update .gitignore to include additional file types
    Added entries for Python, KiCad, and OS junk files.
2026-08-30 Fix TestPoint footprint naming
2026-08-30 Make KiCad fabrication paths portable
    [KiwiDrive.kicad_pcb]
2026-08-30 Standardize Fusion 360 folder naming
    [2020_Aluminum_Extrusion_Mounting_Spacer.f3d, Battery_Mount_Assembly.f3d, Front_Left_Base_Plate.f3d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]
2026-08-30 Add generated Kiwi robot description package
    [Kiwi_Drive_Full_Assembly_Copy_Copy.urdf, Kiwi_Drive_Full_Assembly_Copy_Copy.urdf.xacro, Lidar_Mounting_Plate_collision.stl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]
2026-08-30 Fix ROS 2 control configuration
    [ros2_controllers.yaml]
2026-08-31 Rename robot description package
    [Kiwi_Drive_Full_Assembly_Copy_Copy.urdf, Kiwi_Drive_Full_Assembly_Copy_Copy.urdf.xacro, Lidar_Mounting_Plate_collision.stl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]
2026-09-15 Set MIN_PWM to 0 for motor control
    Changed minimum PWM value to allow for zero speed.
